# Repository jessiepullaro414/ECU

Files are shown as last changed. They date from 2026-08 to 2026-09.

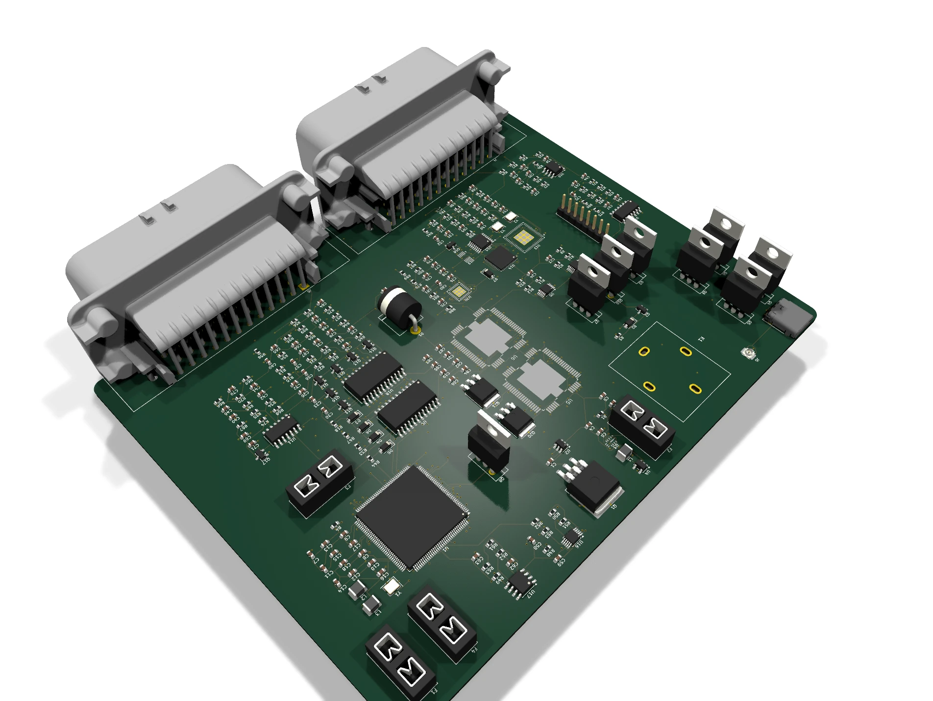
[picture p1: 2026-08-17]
ecu-pcb/render-angled.webp

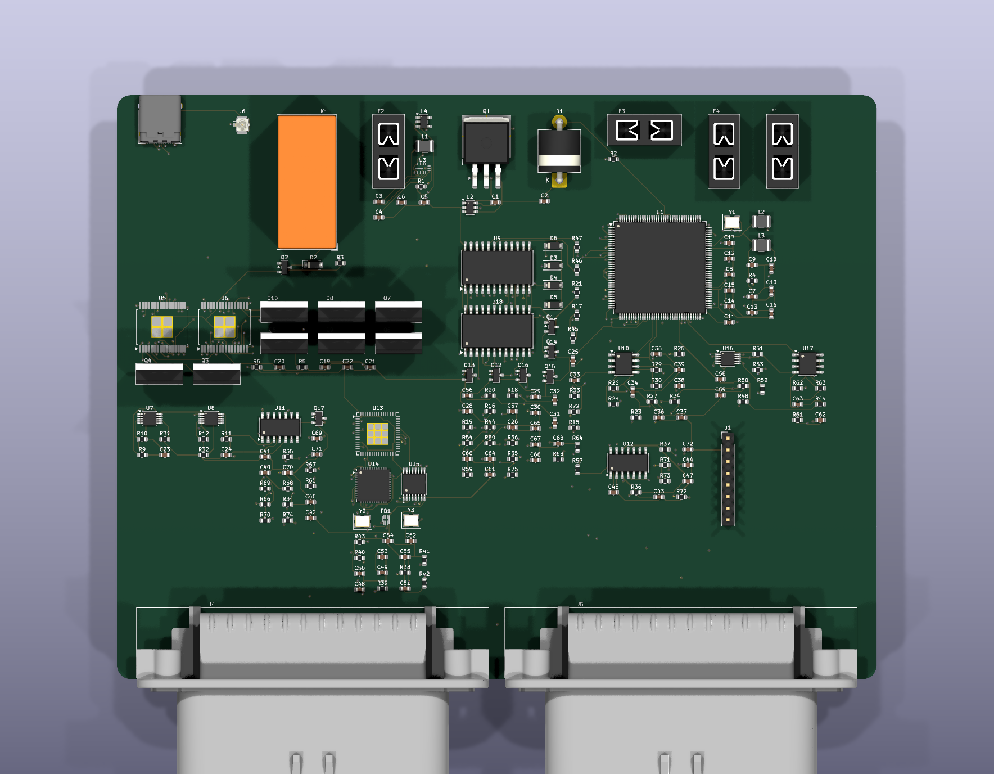
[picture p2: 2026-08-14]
ecu-pcb/ecu_8layer.png

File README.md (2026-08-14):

# ECU

This is the repo for the ECU PCB and firmware — an NXP MPC5606B-based engine
control unit, built with the same real, register/datasheet-verified
discipline throughout (see each subproject's own README for the full,
honest ledger of what's confirmed vs. still open).

- [`ecu-firmware/`](ecu-firmware/README.md) — MPC5606B (e200z0h core)
  register-accurate C/assembly firmware: clocks, SIUL2, DSPI, ADC, eMIOS
  injection/ignition timing, FlexCAN, INTC, SWT watchdog, and drivers for
  the L9779WD-SPI injector/ignition ICs and CJ125 wideband O2 front end.
- [`ecu-pcb/`](ecu-pcb/README.md) — 8-layer, 172.5×114.4mm KiCad board
  (224 parts / 236 nets), fully routed and DRC-clean, built with a
  script-driven generate → route → verify pipeline.

Run `python buildWholeProject.py` from this directory to build both:
schematic → PCB placement → autorouting → DRC for the board, and a
real per-file compile check for the firmware if a PowerPC-EABI/VLE
toolchain is available (see the script's own header for exactly what it
does and does not claim to produce).

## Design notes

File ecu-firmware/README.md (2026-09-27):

# ECU firmware — starting skeleton

Companion firmware project for [`../ecu-pcb`](../ecu-pcb) (the standalone
automotive ECU board). This is **not a working ECU** — it's a real,
compilable-shaped skeleton laying out the actual architecture, with the
hardware-verified facts (pin numbers, SPI protocol, register maps) kept
separate from the genuinely unimplemented parts, so the boundary between
"you can trust this" and "this still needs the reference manual open" is
explicit rather than blurred.

## What's real vs. what's a TODO

**Real, verified this session, safe to build on:**
- Every pin/channel number in [`inc/ecu_pins.h`](inc/ecu_pins.h) — a
  direct transcription of `../ecu-pcb/build_schematic.py`'s own
  `MCU_USED`/`MCU_EMIOS` dicts, the same source of truth the PCB was
  generated from.
- The MC33810 SPI frame format and fault-register map in
  [`inc/mc33810.h`](inc/mc33810.h) — read directly from the real
  datasheet (MC33810 Rev. 11.0, 8/2014) this session, not remembered.
- The confirmation that injector/ignition **firing** goes through the
  dedicated DIN0-3/GIN0-3 parallel pins, not SPI — SPI is
  configuration and fault-readback only. This matches how the board
  itself is wired and shapes the whole real-time architecture below.
- **The eMIOS unified-channel driver** ([`inc/emios.h`](inc/emios.h),
  [`src/emios.c`](src/emios.c)) — a real, working register layer, not a
  stub. Downloaded the actual NXP MPC5606BK Reference Manual (964
  pages) this session and confirmed, by rendering the real register
  diagrams to images and reading them directly (not the raw PDF text
  extraction, which shuffles this document's tables badly enough to be
  actively misleading): both eMIOS base addresses, the per-channel
  register offset formula, the complete EMIOSC[n] control-register bit
  layout, and OPWFMB mode's real encoding — the double-buffered PWM
  mode that's the actual reason `emios_set_pulse_width()` can safely
  re-arm a channel's pulse width mid-cycle without glitching whatever
  pulse is currently firing. `injection.c` now calls this for real.
- **Pin muxing is fully real now** ([`inc/siul2.h`](inc/siul2.h),
  [`src/siul2.c`](src/siul2.c)) — `pinmux_init()` configures every one
  of the 62 real pins in `ecu_pins.h`, not a mechanism waiting on data.
  Built by matching each pin's real 144-LQFP package number against
  Reference Manual Table 4-1 ("Functional port pins", pages 55-74),
  extracted via positioned-text coordinates (the flat text extraction
  shuffles this table's columns) and cross-checked against each pin's
  already-known real signal name from `ecu_pins.h` — all 62 matched
  exactly once, none guessed. Fell out a real, previously-unconfirmed
  formula: PCR index = port_offset×16 + pin-within-port (A=0…G=6),
  confirmed across every port this board's pins actually land on.
- **Clock/mode bring-up is fully real now** ([`inc/clocks.h`](inc/clocks.h),
  [`src/clocks.c`](src/clocks.c)) — `clocks_init()` is a complete,
  callable RESET→SAFE→DRUN→RUN0 sequence, not a stub. Real pieces:
  FMPLL's base address, IDF/ODF/NDIV divider fields, and S_LOCK;
  `ME_MCTL`'s two-write mode-transition mechanism (key `0x5AF0` then
  inverted key `0xA50F`); `ME_RESET_MC`/`ME_SAFE_MC`'s real SYSCLK
  field; and `ME_GS`'s status bits for polling a transition to
  completion. Two real findings worth recording:
  - Caught a real mistake before it shipped: FMPLL CR's upper 16 bits
    were first transcribed from text extraction alone and put S_LOCK
    at the wrong bit. Re-rendering that half as an image and reading
    it directly caught it.
  - `ME_DRUN_MC` and `ME_RUN0_MC`…`ME_RUN3_MC` genuinely have no
    SYSCLK field of their own (confirmed visually, not a page-break
    artifact) — resolved by reading section 8.4.3.12 "System clock
    switching": a mode with no SYSCLK field has nothing to switch to,
    so the source configured in SAFE mode simply carries forward.
    `clocks_init()` sets `ME_SAFE_MC.SYSCLK=PLL` once and relies on
    that.
  - `ME_GS`'s field-name row for bits 0:15 is genuinely missing from
    the source PDF (confirmed via raw positioned-text extraction, not
    a rendering issue) — recovered by cross-referencing the real field
    order (Table 8-4), each field's real bit-width, and the real reset
    value, which only fit together one way.
  - **`clocks_init()` is now actually called for real** from `main.c`'s
    `hardware_init()` (it wasn't, for the rest of this session — this
    was the single most-referenced open gap in the whole project, since
    it silently blocked a real DSPI baud rate, ADC power-up delay, and
    FlexCAN bit timing too). What unblocked it: `../ecu-pcb`'s own
    schematic already documents a real, deliberate 8 MHz crystal
    decision from the PCB design phase (not invented for this pass);
    combined with the FMPLL chapter's own real reference/VCO range
    constraints (4-16 MHz / 256-512 MHz, Section 6.7.2) and this
    manual's own confirmed 64 MHz max core frequency (its introduction,
    not assumed), real divider values fell out:
    `ECU_FMPLL_IDF/ODF/NDIV = 0/2/60` (`clocks.h`), giving a 60 MHz core
    clock — deliberately short of the 64 MHz max, not pushed to the
    edge, given the FMPLL chapter's own note that there's no hardware
    check against an out-of-range frequency.
  - **Follow-up in the same pass: MC_CGM's peripheral clock dividers,
    also real now** (`clocks.h`'s `CGM_SC_DC0` — Chapter 7, Figure 7-5,
    visually confirmed). The real 60 MHz core clock feeds three
    independently-divided "Peripheral Set" clocks; Table 6-1 confirms
    DSPI/FlexCAN are both Peripheral Set 2 and ADC/eMIOS are both
    Peripheral Set 3, and `CGM_SC_DC0`'s own real reset values (all
    three divider-enable bits = 1, all three divide fields = 0) mean
    both sets run **undivided at the real 60 MHz core clock** by
    default — this driver never writes that register, so the reset
    default is what's live. **Still open, honestly, not assumed:**
    each individual peripheral also has its own clock-gating selection
    (`ME_PCTL[n]`/`ME_RUN_PCn`, Chapter 8) that could in principle
    leave it un-clocked in RUN0 regardless of its Peripheral Set's own
    divider — this session located the real register addresses (cross-
    checked between two independent tables) but did not find/confirm
    `ME_RUN_PC`'s own reset bit values, so whether DSPI/FlexCAN/ADC/
    eMIOS are gated ON by default is plausible (matches every other
    "just works out of reset" MC_ME default seen this session) but not
    proven. This only affects whether a peripheral is clocked *at all*,
    not *at what rate* — the real 60 MHz figure above is unconditional
    once a peripheral is clocked.
    **Update (later pass): confirmed this really can't be proven from
    this source.** Chapter 8 (pages 144–177) was checked end to end —
    its own register-description subsections stop at
    `ME_HALT_MC`/`ME_STOP_MC`/`ME_STANDBY_MC`; there is no bit-diagram
    section for `ME_RUN_PCn`/`ME_PCTL[n]` anywhere in it, even though
    Table 8-3 lists their addresses and Chapter 6 explicitly promises
    "See the ME_PCTLn section in this reference manual for details" —
    a real, internal forward-reference in this manual to a section that
    was never actually written into this document. Genuinely absent,
    not a search miss; see `clocks.h`'s file header for the full note.
- **DSPI (SPI bus) is fully real now** ([`inc/dspi.h`](inc/dspi.h),
  [`src/dspi.c`](src/dspi.c)) — `dspi_init()`/`dspi_transfer()` are a
  complete, real, blocking master-mode driver, not stubs, and
  `mc33810_transfer()` (`mc33810.c`) calls it for real — no longer a
  stub either. Real pieces, all visually confirmed against Chapter 26's
  own register diagrams: MCR's MSTR/DCONF/MDIS/HALT/CLR_TXF/CLR_RXF,
  CTARn's CPOL/CPHA/FMSZ/baud fields, SR's TCF/TFFF/RFDF/w1c behavior,
  PUSHR/POPR's real 16-bit frame format. Three real findings worth
  recording:
  - This board's chip selects are plain GPIO, not DSPI's own hardware
    PCS0-5 lines — confirmed directly from Table 4-1 (none of this
    board's real CS pins carry a CS0_x-family alternate function).
    `dspi_transfer()` is therefore a bare frame primitive; CS toggling
    lives in `mc33810_transfer()`.
  - `SPI_SIN`'s (PA[12]) alternate function — flagged last pass as a
    corrupted, unconfirmed table cell — turned out not to be corrupted
    at all: `SIN_0` isn't AF-selected on this pin, confirmed by a
    document-wide search showing the string "SIN_0" appears exactly
    once in the entire 964-page manual (this same table row), unlike
    `SIN_3`/`SIN_4` which each have a real PSMI (Peripheral Selection
    Multiplex Input) register offering a genuine choice between two
    candidate pins. The existing GPIO-input configuration for this pin
    was already correct.
  - Found and fixed a real, previously-dormant bug: `ecu_pins.h`'s
    `PIN_SPI_CS_*` constants are 144-LQFP package pin numbers (matching
    every other constant in that file), but driving a pin as GPIO
    needs a PCR index — a different numbering, the same distinction
    `pcr_configure()` already carried a warning about. This was inert
    while `mc33810_transfer()` was a stub; wiring it up for real would
    have silently toggled the wrong pin. Fixed by adding
    `siul2_pcr_for_pin()` (`siul2.c`/`siul2.h`), a real runtime lookup
    against the same `PINMUX_TABLE` `pinmux_init()` already uses, so
    every caller keeps using the package-pin numbers `ecu_pins.h`
    already establishes as this project's convention.
  - The MC33810's real SPI clock mode (CPOL=0, CPHA=0) came directly
    from its own datasheet's Serial Clock Input description ("SI data
    is latched...on the rising edge of SCLK...SO...shifts out on the
    falling edge") — not assumed from a generic SPI default.
  - **`MC33810_CTAR0`'s baud rate is now real too** (a later pass, once
    the system clock gap closed) — 937.5 kHz, computed from the real
    60 MHz DSPI_0 peripheral clock and PBR's own real inline prescaler
    table (Table 26-5: values 2/3/5/7, not previously looked up).
  - **The "VDD=3.3V not confirmed" flag is resolved** (a later pass) —
    not by finding a separate 3.3V row, but by finding there isn't one:
    the datasheet's own Dynamic Electrical Characteristics table (Table
    5) states its values apply across "3.0V ≤ VDD ≤ 5.5V", a single
    spec covering this board's real 3.3V. The "1.0 MHz, 5.0V" figure
    previously read as a rating turned out to be the ATE test
    condition for guaranteed-by-design parameters (its own footnote
    says so), not a reduced real limit.
  - **Real `tLEAD`/`tLAG` values found, plus a previously-unknown real
    `tSTR` constraint** (same later pass) — Table 5's own "SPI DIGITAL
    INTERFACE TIMING" section: tLEAD ≥ 100ns, tLAG ≥ 50ns, and a real
    minimum 1.0µs gap required *between* separate transfers (tSTR,
    "Sequential Transfer Rate") that this project didn't know existed
    until this pass. `mc33810_transfer()` now runs a real, conservative
    busy-wait around every CS edge and between transfers, computed
    against this board's confirmed 60MHz core clock — closing what had
    been a standing TODO since the driver was first written.
  - **Most of Table 22's bit-level register layout is real now too**,
    not just the fault registers (a later pass) — found by rendering
    the register-address column header at the same crop/scale as each
    data row and tracing bit boundaries straight down against it (the
    same table had previously been dismissed as too garbled to trust).
    Mode Command and LSD Fault Command registers are fully real,
    high-confidence (`MC33810_MODE_*`/`MC33810_LSD_*`, `mc33810.h`).
    One real self-correction worth recording: a first pixel-count pass
    misplaced the LSD register's 3-bit fault-operation field at bits
    11:8 with a spare reserved bit at 7; re-deriving field widths from
    the total real bit budget (12 bits = 3+1+4+4, not 4+1+... which
    doesn't divide evenly) caught it and placed it correctly at bits
    11:9 with bit 8 reserved — the same "don't trust one read" discipline
    this project has used throughout catching itself again. Spark
    Command and DAC Command registers got real field *names* and
    *order* confirmed, but not exact bit-width splits for their
    multi-bit fields — left as real, generic 12-bit payload setters
    rather than fabricated sub-field macros.
  - **Update (later pass): a real address-space bug found and fixed,
    plus every remaining named MC33810 register gap closed.** Re-opened
    Table 21 ("SPI Command Message Set") — the datasheet's *write*
    command table, distinct from Table 22's *readback* table — and
    found it uses a completely different 4-bit top-nibble address for
    the same-named registers (e.g. Spark Command's real write address
    is `0x4`, not the `0x8` this file had previously taken from Table
    22). This wasn't a guess: Table 21's own "hex" column is internally
    self-consistent with its own 4 binary control-address bits on every
    row, and independently corroborated by repeated, non-tabular prose
    elsewhere in the datasheet ("...SPI Command Message Spark command
    (Command 0100, hex 4)..."). Table 22's addresses turned out to be a
    *separate*, real address space — the "Internal Register Address"
    used only inside the generic Read Registers Command's own payload
    to select what gets echoed back on SO, not a write address at all;
    its own header text says as much ("Next SO Response to HEX1 to HEX
    A Commands..."). The two spaces differ by a consistent, real `+4`
    offset for the 10 registers appearing in both. Every
    `MC33810_ADDR_*` constant except `ALL_STATUS` (which happens to
    coincide, `0x0`, in both spaces) was wrong for writing — renamed
    and split into `MC33810_WCMD_*` (real write address) and
    `MC33810_RADDR_*` (real internal register address) to make the two
    spaces impossible to conflate again. Along the way, also found and
    fixed a second, related bug: `mc33810_read_status()`'s All Status
    read was sending an all-zero `0x000` payload where Table 21 shows
    the real required command bits are `0xA00` — never actually
    triggered on real hardware, since no board has been fabricated yet,
    but a real bug regardless. Table 21's own bit-diagram also gave
    real, visually confirmed, full bit-width layouts for every register
    this project had previously left as generic 12-bit setters or not
    reached at all: Spark Command, DAC Command, GPGD Short Threshold
    Voltage Command, GPGD Short Duration Timer Command, GPGD Fault
    Operation Select Command, and PWM0-3 Freq & DC Command — closing
    every one of the previously-named MC33810 gaps in this ledger
    except the Clock Calibration Command's own separate 32µs CS-pulse
    protocol (real, documented, but genuinely needs a dedicated
    CS-pulse primitive this driver doesn't have yet). One real,
    deliberately unresolved discrepancy surfaced and was *not* silently
    picked: Table 10 lists DAC Command's Overlap Setting default
    (`<100>`) as 35%, but Table 21's own default annotation for the same
    field/same code says 50% — both numbers are transcribed honestly in
    `mc33810.h` rather than one being guessed as correct.
- **MC33810 replaced by ST L9779WD-SPI** ([`inc/l9779.h`](inc/l9779.h),
  [`src/l9779.c`](src/l9779.c)) — a real part-obsolescence event, not a
  scope choice: the MC33810 hit **Last Time Buy** status (confirmed via
  DigiKey: last order date 2027-04-30, ~205 units left, no
  NXP-recommended replacement — see the `mc33810-end-of-life` memory).
  No true pin/footprint-compatible drop-in exists (the whole "narrow
  scope" IC segment has moved to bigger, more integrated engine-
  management ICs); L9779WD-SPI (HiQUAD-64, confirmed **Active**, 500
  units in stock) was chosen as the best-targeted real alternative,
  with real precedent — [rusEFI](https://github.com/rusefi/kicad6-libraries/blob/main/L9779WD-SPI.kicad_sym)
  maintains a real KiCad symbol for this exact part. `mc33810.h`/
  `mc33810.c` are kept in the codebase as reference for their own real
  register-map research but are no longer called from `main.c`.
  Real, genuinely different SPI protocol (ST DocID027721 Rev 2, Section
  6.16, read via a Wayback Machine snapshot since ST's live site and
  every mirror tried blocked or timed out automated fetches this
  session): a **5-bit address + 8-bit data + odd-parity-bit** 16-bit
  frame, not MC33810's 4-bit-address/12-bit-payload split. Real,
  critical gotcha caught before it became a live bug: outputs default
  to disabled (`OUT_DIS=1`) after reset — any control-register write is
  silently ignored until the real `START_REACT` command's `START` bit
  is sent, which `l9779_init()` now does for both chips automatically.
  Real, confirmed register map for this board's actual scope:
  `CONTR_REG1` bits 7:4 = `CMD_OUT1-4` (this board's 4 real injector
  channels), `CONTR_REG2` bits 3:0 = `CMD_IGN1-4` (4 real ignition
  channels), `DIA_REG1` = 2-bit-per-channel fault readback for OUT1-4
  (00=short-to-ground, 01=open load, 10=short-to-battery, 11=OK) — same
  real fault-encoding shape as MC33810's, different bit positions. Real
  SPI timing (Table 53: fop max 8MHz, tlead 525ns, tlag 50ns, tcsn
  640ns, tnodata 1.5µs — all genuinely different numbers from MC33810's)
  lives in its own new `DSPI_0` CTAR2 profile (`dspi_configure_ctar()`),
  not reused from MC33810's CTAR0, via the same generic multi-CTAR
  mechanism CJ125 already proved. Real, deliberately unused features
  (available for a later, separate decision — see the plan file's
  redesign section): a built-in VRS sensor interface (only one channel
  per chip, can't replace all 3 of this board's MAX9924s anyway), a
  built-in CAN transceiver, K-Line, a main relay driver, and a 4-channel
  stepper driver.
  **Update (later pass): a real, critical correctness bug caught by
  reading the functional-description prose, not just the register
  tables.** Both LSa (`OUT1-5`, injectors) and the ignition pre-drivers
  (`IGN1-4`) are driven by the real logical **AND** of their own SPI
  control bit and their own dedicated parallel input pin (Sections
  6.8.1/6.10.1 — "They are driven by logical-AND of SPI control bit and
  dedicated parallel input," stated near-verbatim for both). MC33810
  worked differently (real, confirmed **OR** logic — the parallel pins
  alone were already sufficient). Since `CONTR_REG1`/`CONTR_REG2`
  real-reset to all-OFF, this board's real eMIOS-driven parallel firing
  pins would have toggled correctly on real hardware and still never
  fired anything, silently, until this was caught — `l9779_init()` now
  permanently enables all 4 real channels' SPI side at startup
  (`CONTR_REG1`/`CONTR_REG2` = `0x0F`), after which the parallel pins
  have full, unblocked real-time control. Same pass also confirmed
  `IGN1-4` is a genuine IGBT gate pre-driver — Section 6.10.1's own
  opening line: "They can drive IGBT Darlington transistors" — closing
  the real, previously-open question of whether it's a true drop-in
  match for MC33810's `GDx`.
  **Update (later pass): a real hardware dependency this driver can
  neither detect nor work around, worth knowing before debugging a
  "firmware sends everything correctly but nothing fires" symptom.**
  `IGN1-4`'s pre-drivers are supplied from the chip's own `VDD5` rail
  (Table 28 lists `VDD5` 4.9-5.1 V as their supply voltage range and
  specifies their short-to-battery detection thresholds relative to
  it), and `VDD5` is a linear regulator that only exists if an
  **external NMOS pass transistor** and an external charge-pump
  capacitor are fitted — the feature list says "5 V precision voltage
  regulator (±2%) with external NMOS", and Table 13 lists both as
  *required* external components. Those were genuinely absent from
  `ecu-pcb` until a later pass fitted them for real (`Q20`/`Q21` +
  `C82`-`C87`) — before that, this board would have had no ignition
  drive at all despite perfectly correct SPI and parallel-pin timing.
  Two more real behaviors now documented in `l9779.h` because they
  affect how firmware should interpret a dropout rather than what it
  should write: the charge pump's real default is *conditional*, not
  always-on (Section 6.7 — active below 12 V Ubat, or permanently via
  the `capful` bit; the default is genuinely correct for this board and
  needs no firmware action), and above a 28 V Ubat overvoltage it
  "will be switched off automatically no matter the `cp_off` bit
  status" — so ignition dropping out during a real load-dump excursion
  is designed protection, not a fault to retry through.
  **Real, named gaps, not guessed:** the parity bit's own calculation
  isn't confirmed from the text read this session — every frame sends
  parity=0, a real placeholder; whether `DO`'s data is same-frame or
  one-frame-delayed relative to `DIN`'s address isn't confirmed either
  (`l9779_read_dia1()` defensively reads twice, same pattern as
  `mc33810_read_status()`); IGN1-4's own real fault-diagnosis register
  wasn't located in the pages read, so ignition fault readback isn't
  implemented yet; and MC33810's real RSP/RSN (current-sense), FBx
  (coil/collector-sense), and `DRV_OUTEN` (shared kill-switch) pins have
  no confirmed L9779WD-SPI equivalent — flagged in `ecu_pins.h`'s
  `PIN_DRV_OUTEN` comment and the plan file's redesign section as open
  items for the `ecu-pcb` schematic-wiring pass, not resolved here. The
  PCB-side half of this redesign (new footprint, rewired schematic,
  re-routed board) is tracked separately in the plan file and hasn't
  started yet.
- **ADC is fully real now** ([`inc/adc.h`](inc/adc.h),
  [`src/adc.c`](src/adc.c)) — `adc_init()`/`adc_read_channel()` are a
  complete, real, blocking one-shot single-channel driver, not stubs,
  called from `hardware_init()` for both real ADC instances. Real
  pieces, visually confirmed against Chapter 28's own register
  diagrams: MCR's OWREN/MODE/NSTART/PWDN, MSR's status fields, CDR's
  VALID/OVERW/CDATA result format. One real finding worth recording:
  the MPC5606BK has **two independent ADCs** (10-bit `ADC_0`, 12-bit
  `ADC_1`), and which of three Normal Conversion Mask Registers
  (NCMR0/1/2) enables a given channel — and at which bit — follows a
  clean, real formula that fell out of visually confirming all three
  (Figures 28-38 through 28-41): bit *k* of NCMR*n* enables channel
  *(k + BASE)*, BASE = 0/32/64 for NCMR0/1/2. `adc_read_channel()` is
  channel-number-generic (takes a raw ADC channel, not a pin).
  - **The real pin → ADC-channel mapping is done too** (a later pass) —
    `adc_channel_for_pin()` (`adc.c`) real-maps every one of the 15
    real sensor pins in `ecu_pins.h`, and `read_sensors()` (`main.c`)
    now actually populates a real `sensor_readings_t` from them (raw,
    unfiltered — see that struct's own comment for the real filtering
    TODO). The channel-number formula this needed isn't stated
    explicitly anywhere in Table 4-1 — it came from Figure 28-1's own
    block diagram instead: `ADCx_P[n]` = channel *n* (same number on
    both `ADC_0`/`ADC_1` — confirmed the same physical pin wires to
    both), `ADCx_S[n]` = channel *32+n*. All 15 pins land on `ADC_1`
    (12-bit — free extra resolution, since every P[n] pin is wired to
    both instances) except `PIN_ADC_KNOCK1`, whose pad has no P[n] at
    all — only `ADC0_S[0]`/`ADC1_S[4]`, a real, confirmed case where
    the two instances' channel numbers for one physical pin genuinely
    differ (32 vs. 36), not a copy-paste.
- **Crank period tracking is fully real now** ([`src/injection.c`](src/injection.c)) —
  `crank_capture_isr()` computes the real, 16-bit-wraparound-safe tick
  delta between the two most recent crank edges (`ticks_between()`),
  and `cam1_capture_isr()` records a real "has a cam edge been seen"
  flag, both exposed to `main.c` via new real accessors
  (`injection_crank_period_ticks()`, `injection_crank_synced()`).
  `main.c`'s `update_engine_state()` now uses the sync flag for a real
  `ENGINE_STATE_CRANK_SYNC` → `ENGINE_STATE_CRANKING` transition — the
  first real state transition in the engine state machine. This math
  is genuinely frequency/tooth-count-agnostic (plain modular arithmetic
  over `emios.h`'s own confirmed 16-bit capture register width), so
  none of it depends on an unconfirmed number. Two real, complete
  conversion formulas were also added (`us_to_ticks()`,
  `angle_to_ticks()` in `injection.c`) but are deliberately **not**
  wired into `injection_arm_cylinder()` yet — see below for why.
- **FlexCAN is fully real now** ([`inc/flexcan.h`](inc/flexcan.h),
  [`src/flexcan.c`](src/flexcan.c)) — `flexcan_init()`/
  `flexcan_transmit()`/`flexcan_receive_poll()` are a complete, real,
  polled Message-Buffer driver (not the Rx FIFO engine — this board's
  telemetry use case doesn't need FIFO's ID filter table), wired into
  `hardware_init()` for both of this board's real, independent buses
  (CAN0 = FlexCAN_1, CAN1 = FlexCAN_4 — confirmed against
  `../ecu-pcb/build_schematic.py`'s own real routing, which also
  surfaced 4 pins — `PIN_CAN0_TX/RX`, `PIN_CAN1_TX/RX` — missing from
  `ecu_pins.h` since this file was first written; added for real this
  pass, along with their real pin-mux entries in `siul2.c`). Every
  register bit layout used (MCR, CTRL, the Message Buffer C/S+ID word)
  was visually confirmed against Chapter 25's own figures. Real
  findings worth recording:
  - A first pixel-boundary reading of the C/S+ID word figure put the
    PRIO/ID split one bit off; Table 25-4's own text ("only the 11 most
    significant bits (3 to 13) are used") caught and corrected it — a
    real example of this project's "cross-check, don't trust one read"
    discipline catching itself mid-session.
  - The real Rx message buffer **lock mechanism** (Section 25.5.7.3):
    reading an active Rx MB's C/S word locks it against being
    overwritten mid-read; the lock only releases on reading TIMER (a
    real "global unlock" register read) or another MB's C/S word.
    `flexcan_receive_poll()` does the real C/S-then-ID-then-data-then-
    TIMER sequence for exactly this reason — skipping the TIMER read
    would leave the MB locked and silently stop receiving forever.
  - **`FLEXCAN_CTRL_500KBPS`'s bit timing is real too** (a later pass,
    once the system/peripheral clock gaps closed) — a real, standard
    automotive 500 kbit/s target, computed from the real 60 MHz CPI
    clock and Table 25-10's real formulas: `PRESDIV=5` (Sclock =
    60MHz/6 = 10MHz), `PROPSEG=7`/`PSEG1=6`/`PSEG2=3` (20 time quanta
    per bit = exactly 500kbit/s, sample point at a real, standard 80%),
    `RJW=1`. All five field values confirmed within their real valid
    ranges (Table 25-10).
- **eMIOS crank/cam capture channel init is real now** (a later pass,
  `main.c`'s `emios_capture_init()`, called from `hardware_init()`) —
  step 4 of the roadmap, previously entirely unwired. Also resolved in
  the same pass: `EDPOL`'s real sense in SAIC (capture) mode — Table
  27-17's own explicit field description ("1 = Trigger on a rising
  edge, 0 = Trigger on a falling edge"), not just its bit position.
  The existing `emios_init_capture_channel()` logic already matched
  this real meaning before it was confirmed — now verified, not merely
  assumed. One real, honestly-flagged default remains, narrower now:
  this board's crank/cam sensors are real MAX9924 VR-to-digital
  conditioner ICs (`../ecu-pcb/build_schematic.py`), and which specific
  edge lines up with which specific reference tooth (an absolute phase
  question) wasn't found in this session's extraction of its datasheet
  — board/winding-specific, not generic. **Update (later pass):**
  rendered the MAX9924's own Figure 1 timing diagram as an image (text
  extraction didn't preserve the visual relationship between COUT and
  the VR signal) and confirmed COUT is simply a squared version of the
  VR signal's sign relative to BIAS — high through its whole positive
  half-cycle, low through its whole negative half-cycle — so *both*
  COUT edges land on a real zero-crossing, which the datasheet's own
  "Zero Crossing" section ties to "the center of the gear-tooth," not
  just one edge. Capturing on either edge is therefore equally valid
  and can't produce spurious captures; `emios_capture_init()`'s
  rising-edge default is a real, safe (if unproven-absolute-phase)
  choice, not a guess that might not even trigger correctly.
- **INTC (Interrupt Controller) is fully real now** ([`inc/intc.h`](inc/intc.h),
  [`src/intc.c`](src/intc.c)) — closing most of the gap flagged
  immediately above, in the same pass. `intc_init()`/
  `intc_register_isr()`/`intc_dispatch()` are a complete, real
  software-vector-mode driver, visually confirmed against Chapter 18's
  own register diagrams (MCR, CPR, IACKR, EOIR) and cross-checked
  address formulas. Two real findings worth recording:
  - **PSRn (priority select) is genuinely byte-addressable per source**
    despite its own figure grouping 4 sources per 32-bit word for
    display — the field-description text confirms it, the same real
    pattern already seen for `ME_PCTL[n]` (`clocks.h`).
  - **eMIOS interrupt vectors are shared two channels at a time in real
    hardware** — Table 18-10 lists one IRQ number per *pair* of
    channels (`EMIOS_GFR[F0,F1]`, `EMIOS_GFR[F2,F3]`, ...). This
    board's crank (channel 0) and cam1 (channel 1) captures are exactly
    such a pair (IRQ 141); cam2 (channel 18) shares IRQ 150 with an
    unused channel 19. `intc_isr_emios0_ch0_1()`/
    `intc_isr_emios0_ch18_19()` (`injection.c`) check each channel's
    own FLAG bit individually (`emios_flag_is_set()`, a new real,
    side-effect-free read added to `emios.h`) before calling the
    matching real `*_capture_isr()` — the INTC vector alone can't tell
    the channels apart. `main.c`'s `intc_setup()` registers both real
    vectors at deliberately high priorities (15 and 14 — Table 18-5).
  - Software vector mode's real mechanism turned out simpler than
    expected: reading `INTC_IACKR` returns the complete, ready-to-
    dereference address of the current interrupt's own vector-table
    slot (not just a raw source number needing manual math) —
    `intc_dispatch()` is a direct function-pointer call, no INTVEC
    extraction/shifting needed.
  - **What's still real and separately gapped, narrower now than
    before:** the e200z0h core's own exception-vector setup (`IVPR`,
    `IVOR4` — "External Input") and the actual assembly-level interrupt
    prologue/epilogue that makes real hardware jump into
    `intc_dispatch()` in the first place. This is genuinely outside
    portable C and typically supplied by toolchain startup code (e.g.
    S32 SDK) — no local PowerPC-EABI toolchain was available this
    session to write or check it against. Until it exists,
    `intc_dispatch()` is real, correct C that nothing yet calls from
    real hardware — but everything feeding INTO it (vector table,
    priorities, per-channel dispatch logic) now is.
  - **Update (later pass): this gap was researched further and narrowed,
    not closed.** Chapter 15 "e200z0h Core" — the manual's own core-
    architecture chapter — was read in full. Real findings: `IVPR` is
    confirmed SPR 63 (Figure 15-2, the same figure already used for
    `SRR0`/`SRR1`/`CSRR0`/`CSRR1`/`SPRG0`/`SPRG1`); the core is
    explicitly described as a **VLE-only** design (variable-length-
    encoding Power Architecture instructions, not classic/Book E
    encoding) — a real, previously-unflagged constraint meaning the
    still-missing interrupt prologue/epilogue assembly must target a
    VLE-aware toolchain mode (e.g. GCC `-mvle`), not generic PowerPC.
    The individual `IVOR0`–`IVOR15` SPR numbers, however, are confirmed
    **absent** from this specific 964-page manual — an exhaustive search
    for "IVOR" returns only 2 generic prose hits, no numbered table —
    and Section 15.5 says why: it explicitly defers the full
    architecture-defined register set to "the Power Architecture
    specification," a separate document not available this session. Per
    this project's no-guessing discipline, `IVOR4`'s number is
    deliberately still not written into `intc.h` even though it's
    well-established elsewhere in the wider e200/Book E family in
    general knowledge — this project only commits numbers verified from
    a real source actually consulted this session. See `intc.h`'s file
    header for the full writeup.
  - **Update (later pass): closed for real, via a real, different
    primary source.** The e200z759n3 Core Reference Manual (a sibling
    e200-family core, fetched via a real community.nxp.com forum
    attachment) has its own real Table 16 with an explicit `IVOR0`–`15`
    SPR list (`IVOR4`=SPR404, etc.). This isn't the MPC5606B's own
    e200z0h-specific manual, so this project's own discipline required
    real corroboration, not just "close enough" — and got it: every
    other SPR number this codebase had already confirmed from the
    actual MPC5606BK manual (`IVPR`=63, `PIR`=286, `SPRG0`=272,
    `SPRG1`=273) appears in the e200z759 manual's same table with the
    exact same numbers, four independent matches with zero mismatches.
    `intc_ivor_init()` (`intc.c`) now sets `IVPR`/`IVOR4` for real via
    GCC inline `mtspr`, and a real exception-entry assembly stub
    (`src/intc.S` — context save, call `intc_dispatch()`, context
    restore, return-from-interrupt) is written and wired in
    (`intc_setup()`, `main.c`).
    **Update (later pass): the VLE-mnemonic gap is closed too, and it
    caught a real bug.** The actual Freescale/NXP VLE Programming
    Environments Manual (fetched via Wayback Machine) has a complete,
    real VLE instruction mnemonic list (Appendix B) — checked every
    mnemonic `intc.S` uses against it directly. The first version of the
    stub used several bare Book E mnemonics (`lwz`/`stw`/`stwu`/`addi`/
    `rfi`/`mflr`/`mtlr`/`mfxer`/`mtxer`/`mfctr`/`mtctr`/`mtcr`/`bl`) that
    are genuinely absent from the real VLE instruction set and would not
    have assembled on this VLE-only core — a real, confirmed bug, not a
    hypothetical one. Replaced with the real, confirmed VLE forms
    (`e_lwz`/`e_stw`/`e_stwu`/`e_addi`/`se_rfi`/`e_bl`, plus `mtspr`/
    `mfspr`/`mfcr`/`mtcrf`, all independently confirmed real and
    unprefixed under VLE). Real, still-open, narrower risk: individual
    instructions' exact bit-encodings/operand-range limits weren't read
    this pass — a real VLE assembler (still not available this session)
    would be needed to catch a range/encoding mistake at assemble time.
    `e200z0h`'s own exact `IVOR4` field width also remains unverified
    (see `intc.c`'s own comment). This is real, substantive progress,
    not a full toolchain-verified guarantee.
- **CJ125 (wideband O2) driver is real now** ([`inc/cj125.h`](inc/cj125.h),
  [`src/cj125.c`](src/cj125.c)) — a whole new peripheral this session,
  built from the same real Bosch CJ125 datasheet already used during
  this project's PCB design phase. `cj125_init()`/`cj125_transfer()`/
  `cj125_read_ident()`/`cj125_read_diag()`/`cj125_handle_diag()` are
  real and wired into `hardware_init()`/`poll_driver_faults()` —
  closing a TODO that had been sitting since the MC33810 pass. The real
  register map, command bytes, and bit fields came from the datasheet's
  own SPI block-diagram figure (drawn, not stated as plain text — raw
  text extraction alone would have missed it entirely, same discipline
  as every MPC5606B driver header in this project). Two real findings:
  - **CJ125's response pipelining is genuinely different from the
    MC33810's** — confirmed directly from the datasheet's own Read
    Access timing diagram: the response DATA byte is for the *current*
    command, arriving in the same 16-bit exchange (only the leading
    status byte reflects the previous transfer), not delayed a whole
    transfer like the MC33810's pattern this project already knew.
    Missing this would have made every real register read return the
    wrong device's data.
  - **CJ125 needs a different, much faster real baud rate (2 Mbaud max)
    than the MC33810s share on CTAR0** — real, since both chip families
    share one DSPI_0 bus. This surfaced a real gap in the DSPI driver
    itself: `dspi_transfer()` only ever used CTAR0. Fixed generically,
    not with a CJ125-specific hack — `dspi_configure_ctar()`/
    `dspi_transfer_ctas()` (`dspi.h`/`dspi.c`) let any second real
    device share the bus on its own CTAR profile. `CJ125_CTAR1`
    computes a real, conservative 1.875 MHz SCK from the confirmed
    60 MHz DSPI_0 peripheral clock.
- **Sensor filtering is real now** (`main.c`'s `iir_update()`) — a
  simple, real, integer-only exponential-moving-average filter applied
  to every slow-moving sensor (MAP/TPS/IAT/CLT/VBATT/oil-fuel
  pressure/APP1-2/TPS1-2/EGT/ETC feedback) in `read_sensors()`.
  Deliberately excludes knock1/knock2: knock sensors are real
  piezoelectric pickups reporting a fast (multi-kHz) vibration
  transient, not a slowly-varying quantity, so the same EMA filter
  would smear out exactly the signal real knock detection needs — those
  two fields stay raw, unfiltered instantaneous reads, a real,
  intentional distinction, not an oversight. `SENSOR_IIR_SHIFT`'s
  specific time constant isn't tuned against a real running engine yet
  (can't be, until one exists) — same scope boundary as VE tables.
- **Real CLT (coolant temperature) sensor** — *the driver has since been
  folded into the generic sensor table (see "Analog sensors" below); the
  part research below is unchanged and its curve now lives in
  `config/engine.toml` as `[curve.gm_thermistor]`.* The board's CLT sensor was
  swapped to a real GM-style resistive sending unit (DIYAutoTune's
  "GM Closed Element CLT/Oil Temperature Sensor", the same real part/
  curve the sibling [thermo-pcb](https://github.com/jessiepullaro414/Thermo)
  project uses for its own engine-temperature sensor, and genuinely what
  production automotive coolant senders are). Real published curve
  (manufacturer's own page, only 3 points exist): -40°F=100.7kΩ,
  86°F=2.24kΩ, 210.2°F=177Ω. Since only 3 real calibration points exist,
  a single global NTC Beta constant across the full 250°F span would be
  a real approximation error (the two segments' own local Betas differ
  by ~8%, confirmed by computing both) — so a piecewise-Beta model was
  fit per real segment and used to derive a 14-row lookup table at
  design time (the derivation is preserved in
  `ecu-pcb/build_schematic.py` above R24/R25), with
  plain integer linear interpolation at runtime, no floating point,
  matching every other driver here. Readings outside the real calibrated
  range are clamped, not extrapolated (no real data exists past -40°F
  or 210.2°F) — which doubles as free open/short sensor-fault detection,
  same behavior the identical circuit already gives thermo-pcb. This
  redesign also caught and fixed a real hardware bug on the PCB side:
  both IAT's and CLT's pull-ups were wired to +5V despite this MCU's ADC
  domain genuinely running at 3.3V (no separate VRH/VRL pins) — a real
  latent over-voltage risk at cold temperatures, fixed in
  `ecu-pcb/build_schematic.py` (R24/R25 now pull up to +3V3). Not yet
  wired into engine-control logic (warm-up enrichment) — that's real
  engine-specific tuning data, same "needs a running engine" boundary as
  the VE/dwell tables, see `injection.h`'s own note.
- **Real IAT (intake air temperature) sensor** — *same note as CLT: the
  driver is now the generic sensor table, the research below stands.*
  Same session, same real part swap for the board's IAT sensor
  (DIYAutoTune's "GM Open Element IAT Temperature Sensor"). Real, honest
  discrepancy found and resolved while sourcing it, not glossed over:
  the IAT product page's own published 3-point curve shares its first
  two resistance values EXACTLY with CLT's own curve (100.7kΩ@-40°F,
  2.24kΩ@86-87°F) but disagrees on the third point's temperature for the
  identical 177Ω reading (146°F here vs. CLT's 210.2°F) — two genuinely
  different real sensors can't both be right about that. Real evidence
  this is copy-paste content contamination on DIYAutoTune's own IAT
  page, not two authentic curves: a leftover sentence on the IAT page
  itself calls it a "closed-element sensor" despite the product being
  titled/featured as open-element, and taking 146°F at face value would
  imply a per-segment NTC Beta more than 2x CLT's own for the shared
  -40..87°F segment (~7900K vs. ~3800K) — physically implausible for one
  real thermistor, versus CLT's own internally-consistent ~8% spread.
  Conclusion: genuinely the same underlying GM-pattern thermistor
  element as CLT, different physical package (open element for air vs.
  closed/NPT for liquid) — IAT reuses CLT's own
  already-cross-checked curve rather than the IAT page's likely-
  erroneous 146°F figure (kept, separately, as their rated maximum —
  DIYAutoTune's real stated max operating temp for this specific
  package, an honest fact worth keeping even though it's not used as a
  second clamp). R24=4.22kΩ (E96), deliberately different sizing from
  CLT's R25=1.00kΩ: IAT genuinely swings across nearly its whole real
  range in normal use (cold-soak to hot under-hood air), unlike
  thermostatically-regulated coolant, so it's sized via geometric-mean
  (sqrt(177Ω × 100.7kΩ) ≈ 4.22kΩ) for resolution across the full span
  rather than centered on one narrow sub-range.
- **Real EGT thermocouple front end** ([`inc/ads1118.h`](inc/ads1118.h),
  [`src/ads1118.c`](src/ads1118.c)) — a whole new peripheral, driven by
  a real qualification problem rather than a feature request. The
  board's EGT channel used an AD8495 thermocouple amplifier feeding the
  MCU's own ADC; that part carries no AEC-Q100 statement, and **no
  AEC-Q100 dedicated thermocouple amplifier IC exists at all** (MAX31855,
  MAX31856, AD8495, LTC2983, MCP9600 all checked). So the fix was
  architectural: a real AEC-Q100 Grade 1 ADC (TI ADS1118-Q1) reads the
  thermocouple millivolts directly over SPI, and cold-junction
  compensation moves into firmware using the device's own on-die
  temperature sensor. Every register fact here is from TI's SBAS457F,
  read this pass: Config register layout (Figure 44/Table 7), the
  32-bit transaction format (Section 9.5.7.1), and the cold-junction
  data format — 14-bit, **left-justified** in the 16-bit result,
  0.03125 °C/LSB, two's complement (Table 4, with TI's own worked
  examples confirming it). Two real findings worth calling out: the
  `NOP[1:0]` field **must** be `01` or the device silently ignores the
  config write entirely, and this part needs **CPHA=1** (it shifts DOUT
  on the rising edge and latches DIN on the falling), which is why it
  cannot share CJ125's CTAR1 despite both being comfortably slow enough
  — it takes its own CTAR3 at 1.875 MHz, well under this part's real
  4 MHz ceiling. Moving EGT to SPI also freed the analog pin it used to
  occupy (PD[9]) to become this device's chip select, so it cost no new
  MCU pin — `siul2.c`'s own earlier Table 4-1 check had already
  established those Port D analog pads are usable as GPIO.
  **The ITS-90 type-K conversion is now real too** — this was the
  driver's last open gap. The coefficients come from **NIST's own
  Standard Reference Database 60** (the online form of NIST Monograph
  175, DOI `10.18434/T4S888`). Reaching them needed a real browser:
  NIST serves those tables from a Blazor app that renders client-side,
  so plain HTTP fetches return an empty shell — which is exactly why an
  earlier pass recorded this as blocked and declined to invent numbers.
  Only the **inverse** coefficient set is used, because NIST's page
  rounds the forward ones to ~3 significant figures; since the curve is
  strictly monotonic, one table built from the inverse function serves
  both directions — forward for cold-junction compensation, reverse by
  binary search for the measurement.
  [`tools/gen_ktype_table.py`](tools/gen_ktype_table.py) generates
  [`inc/ktype_table.h`](inc/ktype_table.h) (130 entries, −40 to
  1250 °C) and **validates it against two reference points TI quotes
  independently from NIST**: 1250 °C → 50.644 mV and −40 °C →
  −1.527 mV. The generated table hits 50.6436 and −1.5272 — a genuine
  third-party check, not a self-consistency test. Worst interpolation
  error is 0.033 °C, inside NIST's own ±0.05 °C for the inverse
  function, and the integer round-trip the firmware actually performs
  was verified at 0.03 °C worst case. All integer maths, no FPU
  assumed.
- **Real watchdog (SWT) driver, closing a standing TODO** ([`inc/swt.h`](inc/swt.h),
  [`src/swt.c`](src/swt.c)) — a whole new, previously-untouched chapter
  (Chapter 33, "Software Watchdog Timer", 9 self-contained pages) read
  and implemented in full: real register map, real fixed service
  sequence (`0xA602`/`0xB480`), real field bit positions. One real,
  genuinely useful architectural fact this unlocked: SWT's counter
  clock is the undivided 128kHz SIRC, explicitly confirmed independent
  of this board's own FMPLL/system-clock configuration — meaning
  `swt_init()` can run (and does) as the *very first* thing in
  `hardware_init()`, before `clocks_init()`. That directly closes a
  previously-standing TODO in `main()`'s own comment ("a watchdog-forced
  reset instead of a silent halt" on a clock-bring-up failure) — the
  halt loop deliberately never services the watchdog, so a real,
  automatic reset now follows instead of an infinite silent spin.
  `swt_service()` is called once per real main-loop iteration, giving
  this firmware a genuine backstop against a hung main loop that the
  driver ICs' own hardware protections (MAXI/max-dwell, GPGD fault
  handling) can't provide, since those only catch output-stage faults,
  not a hung MCU. Real, deliberate, not-yet-measured choice: a 100ms
  timeout (12800 cycles at the confirmed 128kHz clock), more
  conservative than the chip's own 10ms reset default, since this
  firmware's real main-loop iteration time has never been measured (no
  systick/timer wired up yet). **Update (later pass): `ITR` is now a
  deliberate design choice, not a blocked gap.** SWT's real "Timeout"
  interrupt source was found in Table 18-10 (`SWT_IRQ_TIMEOUT` = IRQ 28)
  — real hardware interrupts can reach C code now (the e200z0h IVOR4
  gap is closed, see the INTC entry above), so nothing mechanical blocks
  wiring an `ITR=1` interrupt-then-reset ISR anymore. `swt_init()`
  deliberately keeps `ITR=0` (immediate reset) anyway: for a hung-
  main-loop backstop on a running engine, giving a genuinely stuck
  system a second timeout window to keep misbehaving is a worse real
  outcome than a fast, deterministic reset — a real safety trade-off,
  not an oversight. `SWT_IRQ_TIMEOUT` is documented and ready if that
  judgment ever needs revisiting. Window mode and keyed pseudorandom
  servicing remain deliberately unused too.

**Deliberately left as TODO, not guessed:**
- **A real CAN message ID/payload map.** `broadcast_can()`'s CAN ID
  (`0x100`) and single-byte `engine_state` payload are placeholders,
  not a defined protocol — this ECU's actual telemetry format is an
  application-layer decision, same scope boundary as VE tables.
- **RPM and any real angle→ticks conversion.** `us_to_ticks()`/
  `angle_to_ticks()` (`injection.c`) are real, correct, generic
  formulas, ready to use — but calling them for real needs two numbers
  this project doesn't have: the eMIOS peripheral's real tick frequency
  (same downstream MC_CGM peripheral-divider gap noted above for
  DSPI/CAN — the *core* clock is real now, this specific peripheral's
  clock still isn't derived from it) and the real crank trigger wheel's
  tooth count/pattern (an engine/sensor hardware choice, not a board
  one). **Both are closed now**: the eMIOS tick frequency is set by
  `[timebase]` in `config/engine.toml` and the time base is actually
  started (`emios_init_timebase()`), and the wheel geometry comes from
  `[crank]`. `injection_arm_cylinder()` converts properly and adds
  injector dead time centrally.
- **Which tooth/cylinder is at TDC** — *closed*. `crank_capture_isr()`
  finds the wheel gap, counts teeth from it, and walks the configured
  firing order to arm the cylinder that is due. What is still genuinely
  unknown is `CRANK_GAP_TO_TDC_DEG`: the angle between the wheel's gap
  and cylinder 1 compression TDC is a physical property of how the
  trigger wheel is fitted, and has to be measured on the engine with a
  timing light. The default in the config is a placeholder.
- Injected conversions, scan mode, DMA, interrupts, the analog
  watchdog, and CTU-triggered conversion (ADC) — real features with
  their own register groups, not touched by this pass's one-shot
  polled driver.
- ~~A real ADC power-up delay~~ — **resolved, a later pass, via a real,
  different primary source.** The Reference Manual explicitly deferred
  electrical timing specs to a separate Data Sheet document — this pass
  found and fetched that real document (MPC5606B Data Sheet, Rev. 5, via
  a Wayback Machine snapshot, since the live NXP URL 404'd the same way
  every other nxp.com doc did this session). Section 3.17 "ADC electrical
  characteristics" gives the real numbers: `tADC0_PU`/`tADC1_PU` (power-up
  delay) = 1.5µs max, `fADC0`/`fADC1` (analog clock) = 6–32MHz. Computed
  a real, worst-case-safe `PDED` value (`ADC_PDED_MIN` = 64 cycles,
  covering the fastest real `fADC` so the delay holds regardless of
  `ADCLKSEL`'s setting) and `adc_init()` now writes it to the real
  `PDEDR` register. **Update: `ADCLKSEL` itself is resolved too** —
  found back in the Reference Manual (Section 28.3.2/Table 28-11): a
  single MCR bit, 0 = half the Peripheral Set clock, 1 = equal to it.
  `adc_init()` never sets it, so it stays at its real default (0) —
  this board's real, exact `fADC` is `60MHz / 2 = 30MHz`, comfortably
  inside the confirmed range. The real exact minimum at that frequency
  would be 45 cycles; `ADC_PDED_MIN` stays at the more conservative 64
  rather than being retuned tighter. The old
  software busy-wait placeholder is gone, not just redundant, since
  `PDEDR`'s own real purpose is to make the hardware itself enforce this
  delay before the next conversion. (Also caught and fixed a real bug in
  this same ledger while re-checking: `PDEDR` was previously miscredited
  with a non-zero reset default alongside `CTR0-2` — re-verified against
  its own diagram, `PDEDR`/`DSDR` both reset to 0; only `CTR0-2`'s
  non-zero reset was ever real.)
- ~~`fmpll_wait_lock()` and `me_transition_to()` have no timeout~~ —
  **resolved** (a later pass): both now return 1/0 (success/timeout)
  after a real, bounded `CLOCKS_WAIT_ITERATIONS` count (`clocks.h`), and
  `clocks_init()`/`hardware_init()`/`main()` all propagate a real
  failure up to a genuinely minimal (halt-only) fault response — see
  `main()`'s own comment for why that's honestly named as minimal, not
  a complete fault strategy. `flexcan_transmit()` and
  `adc_read_channel()` got the same real, bounded-iteration-count
  timeout treatment in the same pass (`flexcan.h`/`adc.c`) — none of
  these are calibrated against a real time unit (this firmware has no
  systick/timer wired up yet to measure real microseconds against),
  just a real, generous iteration count at this board's confirmed
  60MHz core clock, honestly documented as such rather than implying a
  precision they don't have. This is what made it safe to finally call
  `broadcast_can()` from the real main loop (see below) — the whole
  reason a real CAN timeout was worth adding.
- **`ME_PCTL[n]`/`ME_RUN_PCn`'s real reset values** — real register
  addresses located (cross-checked between Table 32-5 and Table 6-1),
  but the actual per-peripheral clock-gating reset state wasn't
  found/confirmed this session (see `clocks.h`'s `CGM_SC_DC0` comment).
  Plausible peripherals are gated ON by default, not proven. **Update:**
  confirmed genuinely absent from this manual, not unresearched —
  Chapter 8 (pages 144–177) never contains a bit-diagram section for
  either register, despite two other places in the same document
  pointing to one that doesn't exist. Closing this for real needs a
  different real source than what's in hand.
- ~~`dspi_transfer()`'s real baud rate~~, ~~MC33810 tLEAD/tLAG timing~~,
  ~~VDD=3.3V confirmation~~ — all **resolved**, see the DSPI/MC33810
  "real" section above for the real numbers and findings.
- ~~The Spark Command and DAC Command registers' exact multi-bit field
  widths~~ — **resolved**, along with ~~GPGD short-threshold/duration
  timer commands~~ and ~~PWM0-3 freq/duty command~~ — see the MC33810
  "real" section above (Table 21's own bit-diagram gave every one of
  these for real, plus caught a real write-address-space bug in the
  process). The MC33810's Clock Calibration Command's own 32µs CS-pulse
  protocol is real and documented (`mc33810.h`) but still not
  implemented — genuinely needs a dedicated CS-pulse primitive, not
  just a command address.
- Everything engine-specific: firing order, VE/dwell/timing tables,
  fuel injector flow-rate scaling. These depend on the actual engine
  this ECU ends up on, not the board.

## Toolchain

**The firmware now compiles and links into a real, bootable image.**
`powerpc-eabivle-gcc` 4.9.4 (built for `ELe200`, the e200 core family
this MCU uses) builds all 18 source files — including the hand-written
VLE assembly in `startup.S` and `intc.S` — and links them against
[`link/mpc5606b.ld`](link/mpc5606b.ld) into `build/ecu.elf`. Run it
from the repo root:

```bash
python buildWholeProject.py --firmware-only
```

Current image: **12,932 bytes of flash** (of 1 MB) and **3,036 bytes of
SRAM** (of 80 KB) — plenty of headroom.

**Watch out for the wrong product.** NXP ships two separate IDEs both
called *S32 Design Studio*, split by architecture, and only one can
build this MCU:

- *S32 Design Studio for **S32 Platform*** is the **ARM** line
  (S32K/S32G). Its bundled GCCs are `arm32-eabi`/`arm64-eabi` only —
  no PowerPC target at all. Having it installed does not help.
- *S32 Design Studio for **Power Architecture*** (S32DS-PA) is the one
  this board needs. It lists MPC5606B as a supported device and ships
  `powerpc-eabivle` GCC under `Cross_Tools`.

`buildWholeProject.py` searches the real S32DS-PA install locations
automatically, and also finds a standalone `powerpc-eabivle-N_N`
toolchain tree; `ECU_FW_TOOLCHAIN_PREFIX` overrides both.

NXP's **TRK-MPC5606B StarterTRAK** kit ships real reference code for

NXP's **TRK-MPC5606B StarterTRAK** kit ships real reference code for
this exact part's peripherals (SCI/CAN/LIN/GPIO) — a genuine reference
worth pulling if any of the remaining named gaps above (real clock
divider values, bit-timing/baud-rate figures, CJ125 support) need a
second real source to check against.

## Engine configuration

Engine-specific facts live in **[`config/engine.toml`](config/engine.toml)**
— cylinder count, crank trigger wheel pattern, firing order, injector
dead time, ignition dwell. Edit that file and run:

```bash
python tools/gen_engine_config.py
```

which validates it and regenerates `inc/engine_config.h` (a generated
file — don't edit it directly). These were previously scattered as
"TODO, needs a real number" comments blocking the firing path, which was
the wrong shape for them: they are not facts to discover from a
datasheet, they are things the person fitting the ECU knows about their
engine.

Putting them in a file read by a generator — the same pattern the BOM
and the Type-K table use — also buys **real validation**. A `#error` in
a header can say "that's wrong"; the generator says *which* cylinder is
duplicated and which never fires:

```
engine.firing_order must list each cylinder 1..8 exactly once
  (repeated: [1]; never fired: [2])
```

That matters because a firing-order typo produces an engine that runs
*badly* rather than one that obviously doesn't run. It also checks teeth
divide 360, missing < teeth, cycle divides by cylinder count, and the
prescaler fits the 8-bit GPRE field.

**The ENGINE values are DEFAULTS, not measurements.** They describe a
common setup (36-1 wheel, 8 cylinders, the usual small-block firing
order) and have not been confirmed against any real engine, because
there isn't one yet. Getting the wheel pattern or firing order wrong
fires cylinders at the wrong time, which is how engines get damaged —
so treat that section as something to fill in deliberately. The
compile-time checks catch a config that contradicts *itself* (teeth that
don't divide 360, more missing teeth than teeth, a cycle that doesn't
divide by cylinder count); they cannot catch one that is simply wrong
for your engine.

Three things this unblocked:

- **Firing-order scheduling is implemented.** `crank_capture_isr()`
  finds the wheel's gap (a tooth period much longer than the last — with
  *missing* teeth removed the gap spans *missing+1* intervals), counts
  teeth from it, and walks the configured firing order to arm whichever
  cylinder is due. Nothing is armed until the wheel's position is known
  *and*, on a four-stroke, the cam has resolved which of the two
  revolutions this is — firing on an unsynced wheel means firing at an
  unknown angle. Verified by simulating the exact logic across four
  configurations (4-cyl 60-2, 6-cyl 36-1, 8-cyl V8, and a 2-stroke
  single that correctly skips cam sync): each fires every cylinder
  exactly once per cycle, in the configured order, evenly spaced.
- **The microsecond → tick conversion is now real.** `us_to_ticks()` and
  `angle_to_ticks()` existed but were never called; injector pulse
  widths were passed into the hardware as though microseconds were
  ticks. Both are wired in now, with injector dead time added centrally
  rather than left to each caller to remember, and a clamp so a pulse
  longer than the 16-bit channel can express is truncated visibly
  instead of silently wrapping to something much shorter.
- **A real bug: the eMIOS time base was never started.** Nothing ever
  wrote `EMIOSMCR`, and `GPREN`'s own field description is blunt —
  *"0 = Prescaler disabled (no clock)"*. The counter had no clock at
  all, so every capture would have read the same value with no error
  reported anywhere. `emios_init_timebase()` now sets the prescaler and
  enables it, following the manual's documented ordering, giving the
  1 MHz / 1 µs-per-tick base the injection maths assumes.
- **Speed-density fuelling is implemented** — `pulse_width_us` was being
  passed as a literal `0`, so every cylinder was scheduled with no fuel.
  [`src/fuel.c`](src/fuel.c) now does the real calculation at the moment
  a cylinder is armed: air mass in the cylinder from the ideal gas law
  (MAP × swept volume × VE ÷ R × intake temperature), fuel mass from the
  target AFR, pulse width from the injector's flow rate. All integer —
  no FPU is assumed anywhere in this firmware — with the intermediate
  air mass held in micrograms in a `uint64_t`, which is necessary rather
  than cautious: at 100 kPa on a 712 cc cylinder the numerator passes
  2×10¹⁰ before the divide, and a wrapped air mass produces a pulse
  width that looks plausible and is badly wrong.

### The VE table

Volumetric efficiency — the fraction of the cylinder that actually fills
— is the measured correction that makes the ideal-gas figure match what
the engine really inhales, and it is the whole reason a tuned map
exists. It lives in `[ve]` in `config/engine.toml` as an RPM × MAP grid
and is bilinearly interpolated. The generator checks both axes are
strictly ascending (the lookup walks them assuming that; a mis-ordered
axis would silently interpolate between the wrong cells), that the table
dimensions match the axes, and that no cell is outside 10–150 % — a VE
outside that is far more likely a typo than an engine, and catching it
here beats discovering it as a lean cylinder at load.

**The shipped table is a starting shape, not a tuned map.** It follows
the general behaviour of a naturally-aspirated engine — poor at low RPM
and light load, best in the midrange, falling off at high RPM — and
describes no particular engine. Running a wrong VE table lean under load
is how pistons get damaged.

Verified on the host against independently-computed floating-point
physics: all 40 table cells round-trip exactly, midpoints interpolate as
expected, off-axis queries clamp to the corner values rather than
extrapolating, and at 3000 rpm / 100 kPa / 40 °C the integer path gives
9272 µs against 9277 µs from the floating-point reference — a 0.05 %
difference, entirely integer truncation.

### The MAP transfer function, and a hardware bug it exposed

`fuel_map_kpa_from_adc()` converts raw counts to kPa across the two
calibrated points in `[map_sensor]`. Writing it is what surfaced a real
defect on the board: `MAP` — along with `TPS`, `APP1`, `APP2`, `TPS1`,
`TPS2`, `OILP` and `FUELP` — is a **5 V ratiometric** sensor feeding a
**3.3 V**-referenced ADC pin through nothing but a 1 kΩ + 22 nF RC
filter. No divider. Everything above 3.3 V converted to `0xFFF`, so the
MAP reading stopped at **~73 kPa of a 105 kPa range**: the ECU went
blind from part throttle upward, exactly where a lean mixture damages
pistons.

That has been fixed in `ecu-pcb` — each of those eight inputs is now a
2:1 divider (4.7 kΩ/4.7 kΩ, values derived against the ADC's own
sampling-network numbers rather than picked; see that project's README
for the full derivation), putting 5.00 V at 2.500 V. Which is why
`adc_counts_at_max = 3103`: 2.500 V of 3.3 V at 12 bits. **Change that
number if you change the divider** — it is the one constant in this file
that describes the board rather than the engine.

**A real bug this work caught**, in the firing-order scheduling
committed just before it: `event.cylinder` was being set to
`firing_order[i] - 1u`, but `cylinder_event_t.cylinder` is documented
1-based and `injector_ch[]`/`ignition_ch[]` are sized to match with a
deliberately-unused slot 0. So cylinder 1 indexed that sentinel — whose
base address is `0` — and cylinder 8 was never driven at all. That is
not "fires the wrong cylinder"; it is an eMIOS register offset written
into the flash boot sector. Found by simulating the ISR on the host and
noticing `ch0` in the armed-channel sequence. Fixed, and
`injection_arm_cylinder()` now rejects an out-of-range cylinder rather
than indexing the sentinel, so the same mistake can't reach a register
write again.

Two supporting pieces came with it. `injection_crank_rpm()` derives
engine speed from the tooth period, normalising the gap tooth's longer
period back to a single interval so RPM is valid at *every* tooth
including the one where wheel sync is established (host-checked: 2997
against a 3000 rpm stimulus, the residual being 1 µs tick
quantisation). And `injection_set_fuel_inputs()` publishes MAP and IAT
from the main loop, because the ISR must not do a blocking ADC
conversion itself — its whole budget at 6000 rpm on a 36-tooth wheel is
278 µs.

What is deliberately **not** implemented, because each needs a running
engine to calibrate and inventing a curve now would be guessing dressed
as configuration: warm-up enrichment from CLT, acceleration enrichment
from TPS rate of change, closed-loop trim from the wideband O2
controllers, and battery-voltage correction of injector dead time (the
board has the VBATT channel precisely for that; the single dead-time
figure in the config is a placeholder for the table).

## Ignition timing

Spark advance lives in `[ignition.advance]` in `config/engine.toml` as
an RPM x MAP table on its own axes, interpolated by the same
`table2d_lookup()` the VE table uses. `inc/ignition.h` / `src/ignition.c`
turn an operating point into an advance and an advance into a crank
angle.

**Before this, every cylinder fired exactly at TDC.**
`fire_angle_for_order_index()` returned the cylinder's nominal TDC angle
straight from the firing order and no advance was ever applied.
Combustion takes real time, so the charge has to be lit *before* TDC for
peak cylinder pressure to land just after it, where it can push. Firing
at TDC makes no useful power and pushes the engine toward detonation.

The table gets its own axes rather than borrowing the VE table's,
because fuel and spark are tuned against different breakpoints in every
real ECU. Adding it also collapsed a duplicate: the bilinear
interpolation was private to `fuel.c`, and a second copy would have been
a second chance for the two tables to disagree about what "halfway
between cells" means. It now lives once in `inc/table.h` / `src/table.c`,
with both tables emitted as `int16_t` cells so one implementation serves
both — spark advance can legitimately be **negative** (retarded past
TDC, which real engines do while cranking), which an unsigned cell could
not express.

**Two guard rails, both verified by deliberately breaking the config:**

A per-cell band, because over-advance is how pistons get holed:

```
ignition.advance.table[0][6] = 460 deg BTDC at 20 kPa / 5000 rpm
is outside -20..60 deg BTDC - almost certainly a typo
```

And a check that the largest advance still fits the scheduling window.
`crank_capture_isr()` arms a cylinder one firing interval before its
TDC, and the spark happens *advance* degrees before that TDC — so an
advance wider than the lead would need scheduling before its cylinder
was ever armed. On a four-stroke eight the interval is 90 degrees and
there is room; the check is reachable on short intervals, and a
two-stroke eight is the honest example:

```
ignition.advance peaks at 46 deg BTDC but cylinders fire every 45 deg,
which is also the scheduling lead. The spark would have to be scheduled
before its cylinder was armed.
```

The shipped table is a **starting shape, not a tuned map** — the same
warning the VE table carries, and it matters more here. Verified on the
host: all 40 cells round-trip exactly, midpoints interpolate as
expected, off-axis queries clamp to the corners, and the table's
physical shape holds across every row and column (advance rises with
RPM, falls with load). The angle wrap is checked too, since cylinder 1
sits at angle 0 and is therefore the common case rather than a corner
case: 26 degrees of advance on a 720-degree cycle gives a spark angle of
**694**, not a negative number.

### The output path is real now

**Two bugs, both upstream of everything else in the firing path.**

`emios_init_opwfmb_channel()` was **never called anywhere**. Only the
three crank/cam capture channels were initialised; all sixteen injector
and ignition output channels were muxed to their eMIOS alternate
function by SIUL2 but their unified channels sat in reset state, so
`injection_arm_cylinder()` was writing match registers on channels that
were in no output mode. Nothing would have fired.

Worse, and found while fixing that: **nothing drove counter bus A.**
Every timing function on this part - capture and output compare alike -
compares against a counter bus, and a bus is just one channel running a
modulus counter and broadcasting it. The capture channels always
selected bus A (`BSL = 00`, which is what their control word writes),
and bus A is driven by Unified Channel 23, which nothing configured. So
every crank and cam timestamp was read from a bus that never counted:
identical values every time, tooth period always zero, wheel never
synced. The engine could not have run even with the outputs fixed.

**DAOC, not OPWFMB.** OPWFMB is periodic PWM - `A` is the period, `B`
the width - so it free-runs and pulses regardless of where the crank is.
Double Action Output Compare is the one-shot mode: per Section
27.4.4.1.1.6 each comparator *"is enabled only after the transfer to
A1/B1 occurs and is disabled on the next match"*, so writing arms one
pulse, it fires once, and the hardware disarms itself until the next
crank event. With `EDPOL = 1` an A match drives the pin high and a B
match low, and mode entry leaves the output at the *complement* of
EDPOL - low - so initialising puts every injector shut and every coil
cold rather than in an undefined state.

That maps onto ignition exactly: releasing the coil **is** the spark, so
the B match is the event the advance was computed for, and A is one
dwell earlier. `DAOC = 0000110` and `MCB Up = 101000b` were confirmed by
rendering Table 27-21 rather than trusting text extraction - the same
render also showed `OPWFMB = 10110b0`, matching the constant this
codebase had already verified independently, which is what makes the
other two trustworthy.

**A third bug fell out of the counter bus.** MCB up mode counts
`1..A1` inclusive (Section 27.4.4.1.1.8: *"the MCB mode counts between
0x1 and A1 register value"*), so with `A1 = 0xFFFF` the modulus is
**65535, not 65536**. `ticks_between()` masked with `0xFFFF` and
therefore gained one tick every wrap. It is a conditional subtract now,
exact for any modulus and free of a divide.

**And a real scheduling constraint, found by simulation.** Arming was
silently failing above 3000 rpm: the range guard was correctly refusing
to schedule a spark the coil could not be charged for. On this
eight-cylinder engine at 6000 rpm cylinders fire every **2.5 ms** while
the configured dwell is **3 ms** - so the next coil must start charging
before the current one has fired. That is unavoidable, not a tuning
error, and a one-firing-interval arming lead cannot express it.
`ARM_LEAD_DEG` is two intervals now, which gives 5 ms at 6000 rpm.
Overlap is safe precisely because every cylinder owns its own eMIOS
channel.

Host-verified: at 3000 rpm ignition pulses are exactly the 3 ms dwell
and injector pulses exactly the computed width plus dead time; every
match value stays inside `1..65535`; pulses that straddle the counter
wrap (`on=57605 off=2243`) still measure the correct width; and 30
events arm per run at every speed from 450 to 6000 rpm.

### Dead time and dwell follow battery voltage

Both were single figures, and `config/engine.toml` already said in both
places that they wanted a voltage table. They are 1-D curves against
VBATT now, interpolated by `table1d_lookup()` - the same axis walk and
clamping the 2-D tables use, factored out so these two did not each grow
a private copy.

**Both are functions of supply voltage for the same physical reason.** An
injector has to build enough solenoid current to overcome the spring and
fuel pressure holding the pintle shut; a coil has to build primary
current to its design figure. Current in an inductor rises at V/L, so a
sagging rail makes both take proportionally longer. Measured against the
shipped placeholder curves:

| | 8 V (starter dragging) | 14 V (charging) | ratio |
|---|---:|---:|---:|
| dead time | 1700 µs | 880 µs | 1.93× |
| dwell | 5000 µs | 2800 µs | 1.79× |

The old fixed 1000 µs dead time would have **under-fuelled by 700 µs per
injection at 8 V** — every cylinder, every cycle, precisely when the
starter is dragging the rail down and the engine can least afford it.

A failed VBATT reading falls back to the nominal 14 V rather than zero,
in `main.c` and again as the module's own default. Zero volts would read
the *longest* entry off both curves and command a hugely overlong pulse
with an overcharged coil — the failure has to fall towards nominal, not
towards maximum.

**The generator checks the physics, not just the shape.** Both curves
must fall as voltage rises; a rising segment is not a tuning choice, it
is backwards:

```
ignition.dwell: 2500 us at 6.0 V but 3000 us at 8.0 V. Current builds
FASTER from a higher supply, so this curve must fall as voltage rises.
```

**This also closed the high-rpm dwell ceiling properly.** Dwell is a
fixed time while the gap between firings shrinks with speed, so above
about 8000 rpm the coil cannot fully charge in the time available. The
scheduler now **shortens dwell to fit** rather than refusing to schedule:
a weaker spark still fires, whereas refusing would act as an abrupt and
undocumented rev limiter. Host-verified — full 2.80 ms up to 7000 rpm,
then 2.69 ms at 8000 and 2.40 ms at 9000.

The curves are **placeholder shapes, not measurements**, flagged like the
VE and spark tables. Real numbers come from the injector's and coil's own
datasheets, or from a bench rig.

### The arming lead is sized from dwell, not fixed as an angle

The first version used a fixed 180-degree lead, and it could not schedule
anything below about **458 rpm** - which is every real cranking speed.
The obvious fix was to slow the timebase to buy counter range, but that
was treating a symptom.

**The lead is a time problem wearing an angle's clothes.** Coil dwell is
a fixed duration - 3 ms is 3 ms at any speed - while the crank covers
wildly different angles in 3 ms. A fixed angle lead must be sized for the
worst case (high rpm, where 3 ms is over 100 degrees) and is then absurd
everywhere else: at 150 rpm, 180 degrees means scheduling **200 ms ahead
to cover a 3 ms coil charge**, and the counter bus only spans 65.5 ms.

`arming_lead_deg()` sizes it from the dwell instead - whole teeth to span
the dwell (rounded up, since the selection test is in exact integer
degrees), plus the advance, plus one tooth of latency margin. It keeps
the 1 MHz timebase, keeps full resolution, and uses **less** counter
range than the fixed lead at every speed:

| rpm | fixed 180 deg | dwell-sized |
|---:|---:|---:|
| 150 | **cannot schedule** | 14 % of counter |
| 200 | **cannot schedule** | 10 % |
| 500 | 85 % | 19 % |
| 3000 | 13 % | 7 % |
| 7000 | 5 % | 5 % |

The generator reports both ends, computed with the firmware's own
arithmetic so the two cannot drift:

```
schedulable from 65 rpm up (counter bus spans 66 ms; lead uses 31% of it at 200 rpm)
dwell of 3000 us stops fitting the lead above about 7450 rpm - shorten
dwell there (a dwell-vs-rpm table) if that is inside your rev range
```

That upper bound is real physics, not a software limit: at 7450 rpm the
gap between firings is shorter than the coil needs, which is exactly why
a dwell-vs-rpm table exists.

**Two real bugs surfaced while proving this out, and both were latent -
neither was introduced by the adaptive lead.**

*The selection comparison was backwards.* It asked whether a cylinder's
TDC was **ahead of** the moving target, when it should ask whether the
target has just **swept past** the TDC. The two agree only when the
arming angle lands exactly on a tooth - which the old 180-degree lead
always did, by luck. Any other lead makes the target step over a TDC, and
an "is it ahead" test then never fires for that cylinder again.

*The selection window was one tooth wide, but the crank does not always
advance one tooth.* Across the wheel's gap it covers `missing + 1` tooth
intervals in a single edge, so on this 36-1 wheel the angles **350 and
710 degrees are never reported at all**. A cylinder whose arming angle
falls there simply never fires. The old lead of 180 degrees happened to
place all eight arming angles on real teeth; a lead of 100 degrees - what
the dwell calls for at 3000 rpm - puts two of the eight squarely in the
gap. The window is now as wide as the arc actually traversed.

Both were confirmed necessary by reverting each in isolation against a
**162-case sweep** (18 speeds x 9 load points, since the lead depends on
both). With the direction reverted, cylinders double-arm at 1800 and 6600
rpm. With the window reverted, five cases silently lose **two of eight
cylinders**. With both in place all 162 cases arm every cylinder exactly
once per cycle, verified over 21 engine cycles each.

That sweep is the reason it was worth testing across load and not just
speed: at 60 kPa the bug is invisible, and a speed-only sweep reports
everything clean.

### What is still not consumed

Injection **phase** — the crank angle at which the injector opens — is
still not a configured value. Pulse width is real and the injector is
scheduled on the counter bus like everything else, but it opens at the
arming point rather than at a calibrated angle. Injection phasing is a
genuine tuning parameter (it decides how much of the charge lands on a
closed valve) and no value for it has been established, so pretending to
one would be worse than saying this.

## Redundancy that can actually fail

The board carries two pedal channels and two throttle channels so a
single sensor failure can be caught by disagreement — on drive-by-wire
nothing mechanical links the pedal to the plate, so a sensor that lies
is a throttle that opens when the driver did not ask.

**The check would have been worth nothing as configured.** `app1`/`app2`
and `tps1`/`tps2` were identical — same band, same slope, same units.
Two channels with the same transfer function detect an open circuit and
nothing else: a stuck track, a track shorted to its neighbour, or a
cross-connected harness reads plausibly on *both*, the two agree, and
the comparison passes. A redundancy check that cannot fail is worse than
none, because it is believed. Production pedals ship a deliberately
dissimilar second track for exactly this reason.

So A3 became three things, not one.

### 1. Sensors have a signal band, not a rail-to-rail assumption

The linear kernel assumed 0 V → minimum and supply → maximum. Real
ratiometric sensors swing about 0.5–4.5 V, and the difference is not
cosmetic:

| MAP sensor output | firmware said | truth |
|---|---:|---:|
| 0.5 V (its minimum) | 19.5 kPa | 10 kPa |
| 4.5 V (its maximum) | 95.5 kPa | 105 kPa |

~10 % at both ends. The worse half is that **a broken wire pulls the pin
to 0 V and read as a perfectly valid 10 kPa** — there was no way to tell
"minimum pressure" from "disconnected" on any linear channel.

`signal_mv` states the real swing, and a `fault_margin_mv` band outside
it turns those dead zones into diagnosis: below the band is a broken
wire or a short to ground, above it is a short to the supply. That is
precisely *why* sensors are specified to swing 0.5–4.5 V instead of rail
to rail. Inside the band but past a calibrated endpoint still clamps —
that is tolerance, not a fault.

### 2. The second track of each pair is deliberately dissimilar

`app2` runs at **half slope** (0.5–2.5 V over the same travel); `tps2`
is **inverted** (4.5 V closed, 0.5 V open). Inverted is the stronger
form — no single failure makes a rising track and a falling track agree.

The generator **refuses** a pair whose transfer functions are not
distinguishable, so this cannot quietly regress:

```
redundant pair app1/app2 is not distinguishable: slopes differ by only
1.00x and run the same direction (need 1.5x, or opposite signs). Two
channels with the same transfer function detect an open circuit and
nothing else - a stuck or cross-connected track reads plausibly on both
and the check passes. Give one a half slope or invert it, as production
pedals do.
```

It also refuses a linear sensor with no `signal_mv` at all, rather than
silently reinstating the old assumption.

### 3. The check itself

`plausibility.c` walks the generated pair table, flags a pair whose
channels are out of band (`PLAUS_FAULT_RANGE`) or which disagree by more
than the configured tolerance (`PLAUS_FAULT_DISAGREE`), and **latches**.
Latching is deliberate: an intermittent connection that disagrees for
one sweep in a hundred is exactly the fault worth catching, and a
live-only flag would read clean by the time anyone looked.

Host-verified, including the case the old configuration could not catch
— a **cross-wired pedal harness**, where both pins carry track 1's
signal. With identical tracks the two channels read the same and agree
perfectly; with a half-slope second track they cannot.

**It detects and latches; it does not yet act.** There is no throttle
controller — the MC33926 H-bridge sits on the board unused — so nothing
can drop throttle authority in response. The rule that controller must
follow is written at the top of `plausibility.c` rather than left to be
rediscovered: limp position on a pedal fault, cut drive on a throttle
fault, and **never** fall back to whichever channel still looks healthy,
because the whole point of the pair is that one reading cannot be
trusted.

## Host tests

`python tools/run_host_tests.py`, and part of every `buildWholeProject.py`
run.

Nothing here can execute on the target — there is no board — so the only
way to run any of it is to compile the portable modules natively and
drive them with a hardware stub. That loop has caught, in order: a
`uint64_t` air-mass overflow that would have produced plausible-looking
wrong pulse widths; a cylinder off-by-one that wrote an eMIOS register
offset **into the flash boot sector**; a crash inside a safety check's
own error path; a scheduling window one tooth too narrow that silently
dropped two of eight cylinders; and a comparison written backwards that
only worked because one arming angle happened to land on a real tooth.

Every one of those was invisible to review and invisible to the
compiler.

They used to be written to a scratch directory, which is wiped between
sessions — so each of those bugs was found by a test that no longer
existed the next time anyone looked. They live in `test/` now. A
regression that has to be re-derived is not a regression test.

| test | covers |
|---|---|
| `test_sensors.c` | conversion kernels, checked against the *retired* CLT/IAT drivers |
| `test_tables.c` | VE, spark, dwell curves; integer fuel path vs floating-point physics |
| `test_plausibility.c` | redundant-pair faults, including the cross-wired harness |
| `test_scheduling.c` | 162 cases — 18 speeds × 9 loads — every cylinder armed once per cycle |

The scheduling sweep covers **both** axes on purpose: the arming lead
depends on dwell *and* advance, so a lead that lands cleanly at one load
can land on the trigger wheel's missing tooth at another. A speed-only
sweep reports everything clean while two of eight cylinders never fire.

## Analog sensors

Every analog channel is described in `config/engine.toml` and converted
by one table-driven module (`inc/sensor.h`, `src/sensor.c`) with three
kernels — `linear`, `voltage`, `thermistor`. Adding a sensor is a config
edit, not a new `.c`/`.h` pair.

This replaced `clt_sensor.{c,h}` and `iat_sensor.{c,h}`: **405 lines
that differed in a pull-up value, a lookup table, and the prefix on
every identifier.** Meanwhile eight channels — TPS, OILP, FUELP,
APP1/APP2, TPS1/TPS2, VBATT — had no conversion at all and were still
raw ADC counts in the main loop, each of which would have wanted its own
file pair. The pattern did not scale. All eleven channels now report
engineering units.

Four things this buys beyond tidiness, and they are the actual reason to
do it:

**The divider stops being a magic number.** Each channel names the real
resistors in front of it and the generator computes where full scale
lands in ADC counts. `MAP_ADC_AT_MAX = 3103` used to be typed in by hand
and would have gone stale the moment the board changed. The generator
now derives it — and derives it *correctly*: the divisor is 4096, not
4095, because the data sheet's Figure 22 defines `1 LSB ideal =
AVDD / 4096`. Using the maximum code instead would bias every reading by
one count. Negligible against a ±6 LSB TUE, but wrong for a number whose
whole purpose is being derived rather than guessed.

**It cross-checks the board.** The generator reads
`ecu-pcb/build_schematic.py` and compares every declared resistor against
the real reference designator — 18 of them at present. Config and board
cannot drift apart silently:

```
sensor.map.divider.r_bottom says 10000 ohm but R94 on the board is
4700 ohm (ecu-pcb/build_schematic.py). One of the two is stale - the
firmware and the board must agree.
```

If `ecu-pcb` isn't beside this project the check is skipped and says so,
so the firmware still builds standalone.

**It refuses a divider that would clip.** This is not hypothetical — it
is the bug this board actually shipped, where eight 5 V sensors fed a
3.3 V ADC through nothing but an RC filter and MAP stopped reading at
~73 kPa of its 105 kPa range. That configuration is now unrepresentable:

```
sensor.map: a 5000 mV sensor through NO DIVIDER AT ALL - it is wired
straight to the pin puts 5000 mV on a pin referenced to 3300 mV.
Everything above the reference converts to full scale, so the top 34%
of this sensor's range would be unreadable.
```

**One unit convention.** Everything is hundredths of a degree Celsius.
The old drivers worked in tenths of a degree *Fahrenheit* while the EGT
path worked in centi-Celsius, which put a `(tenthF - 320) * 50 / 9`
conversion in the middle of the fuel calculation. That is gone.

### One curve, two sensors

CLT and IAT share a single `[curve.gm_thermistor]` rather than carrying
duplicate tables, and that is a finding rather than a convenience.
DIYAutoTune's IAT page publishes a third curve point (146 °F at 177 Ω)
that contradicts the CLT page (210.2 °F at the same 177 Ω) while the
first two points are identical. Two different sensors cannot both be
right about that. The IAT page's own text calls the product a
"closed-element sensor" while selling it as open-element — leftover copy
from the CLT page — and taking 146 °F at face value implies a
per-segment Beta more than twice CLT's own over the shared segment,
physically implausible for one thermistor. Conclusion: the same GM
element in two packages. The config structure now says so directly.
DIYAutoTune's 146 °F is kept as their stated *maximum rated* temperature
for the open-element part, which is a real and different fact.

### What is deliberately not in the table

EGT is a thermocouple behind an SPI ADC needing cold-junction
compensation and a NIST ITS-90 polynomial; knock is a raw AC signal
wanting a windowed transform, not a scalar conversion. Both stay
bespoke — forcing either in would make the table lie about what it can
do.

**The throttle, pedal and pressure ranges are placeholders**, flagged as
such in the config the same way the VE table is. A real TPS/APP does not
swing the full 0–5 V (typically ~0.5–4.5 V) and production practice is to
*learn* the closed and wide-open endpoints rather than trust a datasheet;
no specific oil or fuel pressure sender has been chosen. Those channels
report something meaningful now, but none of them is a calibration.

Verified on the host against the drivers they replaced: thermistor
resistance is bit-identical, temperature agrees within **0.04 °C** (pure
rounding of the old Fahrenheit curve), and MAP reproduces the retired
`fuel_map_kpa_from_adc()` exactly. VBATT reads 14.02 V at a plausible
charging count. Open circuit, bad channel id, and resistance-on-a-
non-thermistor all return their documented sentinels.

## Boot and startup

Two files carry everything between reset and `main()`, and both are
built from the MPC5606BK Reference Manual rather than a vendor template.

**[`link/mpc5606b.ld`](link/mpc5606b.ld)** — code flash 1 MB at
`0x0000_0000`, L2SRAM 80 KB at `0x4000_0000` (Table 31-3). It also
carries two `ASSERT`s that turn silent runtime corruption into
link-time errors, the useful one being an SRAM overflow check so
`.data + .bss + stack` can never quietly exceed 80 KB.

**[`src/startup.S`](src/startup.S)** — the reset entry. Two parts of it
are genuinely easy to get wrong and expensive to debug:

1. **The boot header.** Chapter 5 / Figure 5-2: the SSCM scans each
   boot sector for `BOOT_ID = 0x5A` in bits 8:15 of the word at the
   sector base, then jumps to the 32-bit vector at offset `0x4`.
   PowerPC numbers bits MSB-first, so that word is **`0x005A0000`**.
   Get it wrong and the SSCM finds no valid sector across all five,
   hands over to the BAM, and parks the core in static mode — the chip
   never runs your code and gives no other symptom. The build verifies
   the word actually landed rather than assuming it did.
2. **SRAM ECC initialisation, before the stack exists.** Section 31.5
   is explicit that because ECC syndrome bits power up random, SRAM
   "must be initialized by executing 32-bit write operations prior to
   any read accesses" — including implicit reads caused by sub-32-bit
   writes. A stack frame is read back on the way out, so the stack
   cannot be touched until this is done. The init therefore runs out of
   registers only: no stack, no reads, no calls. It uses `e_stmw` to
   write all 32 registers (128 bytes, 32-bit aligned, even count, as
   Section 31.6 requires) per iteration — 640 iterations covering
   exactly 80 KB, which the disassembly confirms.

`startup.S` also supplies a no-op `__eabi`, which GCC calls at the top
of `main()` on PowerPC EABI targets; the small-data bases (`r13`/`r2`)
and `.data`/`.bss` init it would normally arrange are already done
explicitly in the startup path.

## Real-time architecture

Two timing domains, deliberately kept separate (see `src/main.c` and
`inc/injection.h` for the full reasoning):

1. **Interrupt context** — crank/cam capture only. Decides fire angles,
   arms the next eMIOS event. Nothing else should run here.
2. **Main loop** — ADC sampling, table lookups, MC33810/CJ125 SPI
   polling, CAN, fault monitoring. Feeds the *next* interrupt-context
   decision; never blocks waiting on the current one.

No RTOS in this skeleton — the actual hard-real-time work (pulse
timing) is done by the eMIOS hardware once armed, not by software
scheduling, so a plain main loop is a reasonable real starting point
(the same structure most bare-metal EFI firmware uses). If task
isolation becomes worth the complexity later, **Erika Enterprise** is
the real open-source option for this MCU's e200 core — OSEK/VDX
RTOS, GPL, with confirmed Power-Architecture e200 support for several
MPC56xx variants (MPC5674F, MPC5668G, MPC5643L). The MPC5606B itself
isn't confirmed on their supported list — same "verify, don't assume"
gap as everything else here.

## Open-source reference material (not reusable code)

**rusEFI** is the closest real open-source EFI project in spirit — the
same MC33810 driver-IC pattern this board uses — but it targets STM32
only; there is no Power Architecture support. Its actual firmware code
won't port. Its documented *algorithms* (VE table interpolation,
cranking/warm-up compensation, closed-loop O2 trim structure) are
genuinely worth reading as a reference while writing the table-lookup
logic this skeleton's `update_tables()` stub leaves open.

## Known open items

- **All six driver roadmap steps have real work landed** (see above):
  eMIOS, SIUL2/pin-mux, clock/mode bring-up, DSPI, ADC, crank-period
  tracking, and FlexCAN. Step 4 (eMIOS) is partial (crank/cam capture
  channel init is real, injector/ignition arming deliberately deferred
  — needs real tick values this project doesn't have). Step 5 is
  partial too (period tracking is real, RPM/angle-to-ticks conversion
  is correctly formula'd yet deliberately not wired in). The clock
  chain is now real end to end for DSPI/CAN (60MHz core →
  confirmed-undivided peripheral clock → real, computed 937.5kHz SPI
  baud rate and 500kbit/s CAN bit timing). INTC (Interrupt Controller)
  is real too now — real vector table, priorities, and per-channel
  dispatch for this board's two real, shared eMIOS capture vectors.
  Every blocking wait that used to have no timeout (`fmpll_wait_lock()`,
  `me_transition_to()`, `flexcan_transmit()`, `adc_read_channel()`) now
  has one — real, bounded, iteration-count-based (not calibrated
  against a real time unit, no systick/timer wired up yet, honestly
  documented as such). ~~What's left: ADC's own real settling-TIME
  figure~~ — resolved, see the ADC entry above (real MPC5606B Data
  Sheet, real `PDEDR` value now written). What's left: the
  still-honestly-unconfirmed `ME_PCTL`/`ME_RUN_PC` per-peripheral
  clock-gating reset values (plausible but not proven — checked this
  same new real MPC5606B Data Sheet for `ME_PCTL`/`ME_RUN_PC` too;
  genuinely absent from it as well, real confirmed, not just unfound —
  this specific gap needs a different real source than either document
  in hand). **Update: the e200z0h core's own
  `IVPR`/`IVOR4` exception-vector setup is real now too** (`intc_ivor_init()`,
  `intc.c`, plus a real assembly entry stub, `intc.S`) — see the INTC
  entry above for the full provenance and its own honestly-flagged,
  still-open risks (VLE-encoding and exact `IVOR4` field width, neither
  independently verified this session, no local PowerPC-EABI/VLE
  toolchain available to check either against). The CJ125 (wideband O2) driver is
  real now too, a whole new peripheral this session, closing the
  MC33810-pass TODO — see above.
- `injection_arm_cylinder()` converts microseconds to eMIOS ticks for
  real and adds injector dead time centrally; `crank_capture_isr()`
  decodes the missing-tooth wheel and arms the cylinder due next, with
  a real speed-density pulse width from `fuel.c`. All three previously
  needed numbers (eMIOS tick frequency, wheel geometry, firing order)
  now come from `config/engine.toml` (see above).
- `broadcast_can()` is now called from the real main loop (see above) -
  `flexcan_transmit()`'s real timeout made that safe.
- MC33810 SPI transfer (`mc33810_transfer()`) is implemented with a
  real, conservative baud rate and real tLEAD/tLAG/tSTR timing margins
  (see above) - both previously-open gaps now closed.
- Firing order and the VE table are real and configurable
  (`config/engine.toml`, see above), with the values shipped as
  documented **defaults, not measurements**. No ignition-timing table
  and no dwell *table* exist yet (dwell is a single configured figure);
  both are engine-specific and want a running engine to tune against.
- **The real CJ125 INIT_REG1/2 byte values for this board's actual
  running configuration** — `cj125_write_init1()`/`cj125_write_init2()`
  are real, generic byte setters, but which gain range (`VL`) matches
  the real LSU4.2 sensor's calibration and which pump-reference-current
  code (`PR0-3`) to use needs either a fuller application-note
  extraction (the PRx-to-µA transfer function wasn't in this session's
  excerpt) or bench calibration against a real sensor — neither done.
  Nothing calls the write functions yet as a result. **Update (later
  pass):** a web search surfaced a claimed conflicting value
  (`0x88` for "normal, gain=8×" in a real, widely-used open-source EFI
  project's driver code) — rather than trust an AI-summarized secondhand
  claim, it was checked directly against the real Bosch datasheet's own
  `INIT_REG1` diagram (already rendered this project, `cj125_spi_page.png`).
  The primary source re-confirms this file's existing bit positions
  exactly (`x|PA|x|RA|x|LA|x|VL`, bits 7/5/3/1 reserved) — the claimed
  `0x88` never actually got verified from source (the real fetch was
  blocked), so it doesn't count as a real contradiction. `cj125.h` now
  documents the real, generic formula for a "normal, gain-8×,
  measurement mode" byte (`PA=1` alone = `0x40`) — still not this
  board's specific chosen configuration, that part of the gap remains.
- The CJ125's own real command-byte "hec" (header error check)
  generation algorithm — not reverse-engineered; this driver uses the 6
  real command byte values directly rather than needing it, but no 7th
  command can be synthesized without finding the real algorithm.
- Lambda/AFR conversion from the CJ125's real UA/UR analog outputs —
  those are separate real ADC channels, not covered by this SPI-only
  driver, and weren't cross-checked against `ecu_pins.h` this session.

## Reference material used this session

The real NXP MPC5606BK Microcontroller Reference Manual, Rev. 2,
05/2014 (964 pages) — the primary source for everything in `emios.h`,
`siul2.h`, `clocks.h`, `dspi.h`, `adc.h`, `flexcan.h`, and `intc.h`. Not re-hosted here; if you need it again, NXP's own direct
link 404s in some environments (bot-protected), but it's mirrored at
`dtsheet.com/doc/2288517` and was also fetched successfully via a
regular browser session pointed at NXP's own
`docs/pcn_attachments/16234_MPC5606BRM_Rev2.pdf` when curl's request
was blocked.

The real Bosch CJ125 datasheet (Robert Bosch GmbH, 04/2006) — the
source for `cj125.h`/`cj125.c`, the same real datasheet already used
during `../ecu-pcb`'s own PCB design phase (see that project's own
schematic comments). Landed via a Wayback Machine mirror after direct
fetches were blocked, same real pattern as this project's other
datasheets.

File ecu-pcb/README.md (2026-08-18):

# ECU — standalone automotive engine-management ECU

Companion KiCad project for a from-scratch standalone ECU: drives fuel
injectors and ignition coils directly, closed-loop on engine sensors,
usable across 4/6/8-cylinder engines from a single board, with both BLE
and USB-C as full (not partial) wireless/wired firmware-flashing paths.

Sibling project to [`../manifold-pcb`](../manifold-pcb) (a smaller
Arduino-Nano-pinout automotive sensor board) — this project reuses
Manifold's script-driven, kiutils + kicad-cli-verified generation workflow
directly rather than reinventing it, but is a separate, much larger board:
new directory, new schematic, not built on top of Manifold's layout.

**Status: schematic complete, board placed + fully routed + DRC-clean,
BOM done.** Steps 2-10 are all done. The board is **165.8 × 130.1 mm,
8 layers, 243 footprints, 243 nets**, fully routed (0 unrouted) with GND
planes poured on In1/In3/In6.Cu and +3V3 on In4.Cu — 3729 track
segments and 521 vias. Real `kicad-cli pcb drc` reports **0 errors and
0 unconnected items** — the only remaining findings are the same benign
`lib_footprint_mismatch` warnings this project (and Manifold before it)
has always carried, now 19 of them.

Routing on a board this dense (242 nets, a 0.5mm-pitch H-bridge QFN, 8
layers) sits right at FreeRouting's practical convergence limit:
repeated full regeneration+route cycles land at score ~992-993 with
0-3 residual nets that vary run to run — ordinary autorouter variance,
not a stuck design, and this specific committed board is one of the
runs that landed at a genuine, DRC-verified zero. Widening part spacing
to force convergence was tried and **ruled out** — see "Known open
items".

**Every active part on this board is now automotive-qualified.** The
three that once weren't are resolved: MC33926 was always AEC-Q100
Grade 1 (a stale datasheet revision hid it), the L9779's `VDD5` pass
NMOS became the AEC-Q101 `STD20NF06LAG`, and the unqualified AD8495
thermocouple amplifier was replaced architecturally by an AEC-Q100
ADS1118-Q1, because no qualified thermocouple amplifier IC exists to
swap it for.

The **BOM is generated, not hand-kept** — [`build_bom.py`](build_bom.py)
reads the schematic directly and renders
[`ECU_BOM.html`](ECU_BOM.html), a standalone parts-list page. What
remains before fab is a purchasing pass for live pricing and stock, and
hand-layout of the RF section, which cannot be machine-routed.
**Every part on the board is now a real, specific part** — the 2.4 GHz
balun was the last placeholder, now resolved to a Johanson
`2450BM14G0011T-AEC`.
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

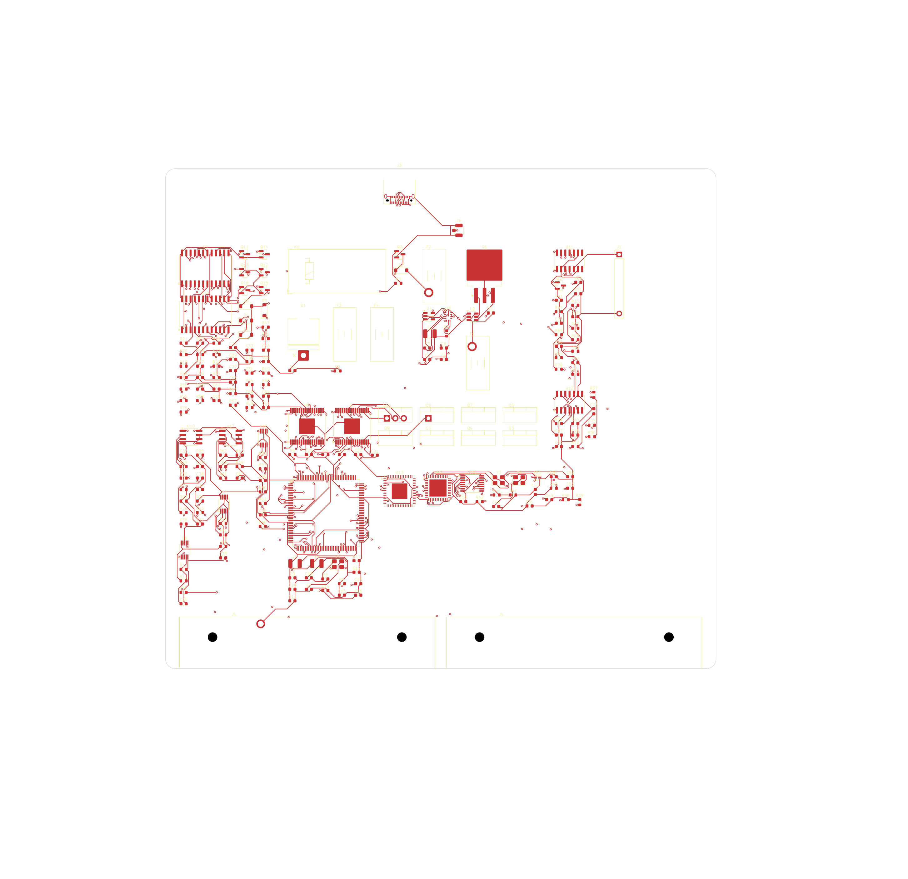
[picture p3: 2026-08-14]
ecu-pcb/ecu_final_2d.png

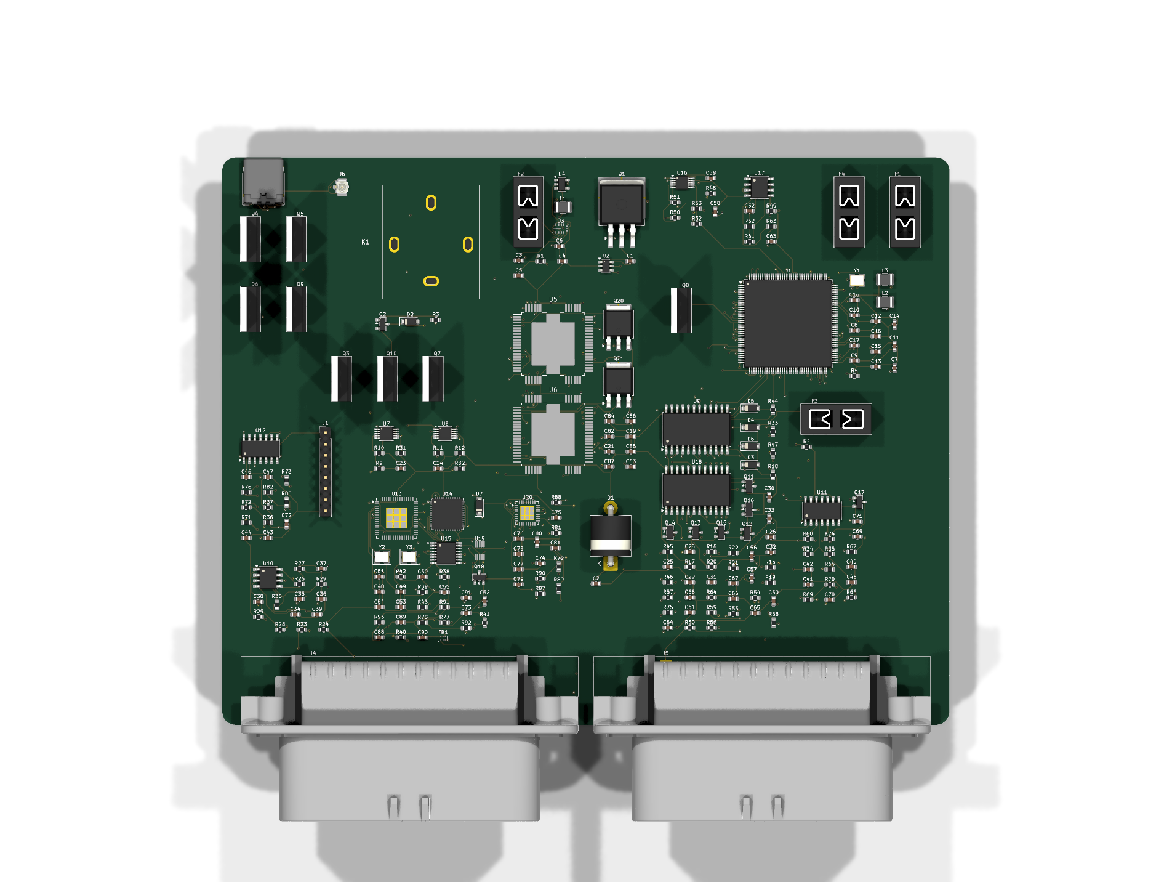
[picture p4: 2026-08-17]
ecu-pcb/ecu_render_top.png

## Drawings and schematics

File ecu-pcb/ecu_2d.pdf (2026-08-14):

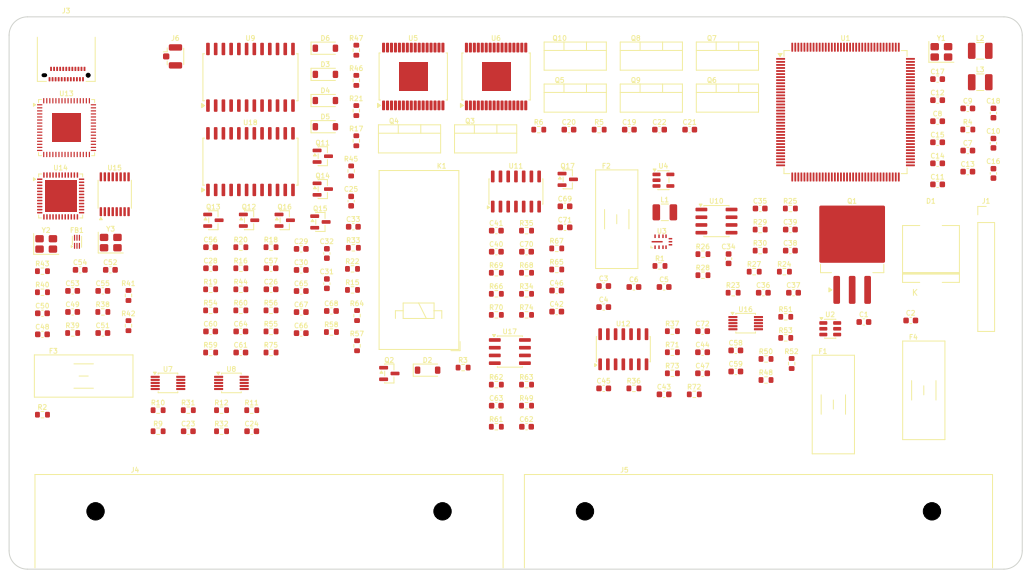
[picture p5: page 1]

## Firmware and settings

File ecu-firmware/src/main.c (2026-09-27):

/*
 * main.c - top-level scheduling loop.
 *
 * Real architecture, deliberately bare-metal (no RTOS) for a first cut:
 * the genuinely hard-real-time work (injector/ignition firing) is done
 * IN HARDWARE by the eMIOS unified channels once armed (see injection.h)
 * - the MCU's job is to keep re-arming them in time, which is a soft-
 * real-time problem a plain main loop + a few interrupts handles fine,
 * the same way most open-source EFI firmware (rusEFI included, per its
 * own architecture docs) structures this. An RTOS (Erika Enterprise is
 * the real open-source option for this MCU's e200 core - see the
 * ecu-firmware README) becomes worth it once there's enough going on
 * that priority inversion between, say, CAN traffic and table lookups
 * becomes a real risk - not needed to get a first cylinder firing.
 *
 * Two real timing domains, kept deliberately separate:
 *   1. INTERRUPT CONTEXT - crank/cam capture ISRs (injection.h). These
 *      decide fire angles and call injection_arm_cylinder(). Nothing
 *      else in this file should be assumed to run between two crank
 *      edges at high RPM - a lot of first-firmware bugs on real engine
 *      projects come from doing too much work in this path and missing
 *      the next tooth.
 *   2. MAIN LOOP - everything that can tolerate a few milliseconds of
 *      jitter: ADC sampling/filtering, VE/dwell/timing table lookups
 *      (the RESULTS feed the next crank-edge decision, the lookups
 *      themselves don't need to happen in the ISR), L9779WD-SPI/CJ125 SPI
 *      polling, CAN broadcast, fault monitoring.
 */
#include <stdint.h>
#include "ecu_pins.h"
#include "l9779.h"
#include "injection.h"
#include "siul2.h"
#include "clocks.h"
#include "adc.h"
#include "flexcan.h"
#include "emios.h"
#include "intc.h"
#include "cj125.h"
#include "swt.h"
#include "sensor.h"
#include "plausibility.h"
#include "ads1118.h"
#include "fuel.h"
#include "engine_config.h"

typedef enum {
    ENGINE_STATE_CRANK_SYNC,   /* waiting for a cam edge to disambiguate 360 vs 720 */
    ENGINE_STATE_CRANKING,     /* synced, RPM below run threshold */
    ENGINE_STATE_RUNNING,
    ENGINE_STATE_LIMP,         /* real fault active - degraded/safe operation */
} engine_state_t;

static engine_state_t engine_state = ENGINE_STATE_CRANK_SYNC;

/* Real, filtered ADC readings - one field per real sensor pin in
 * ecu_pins.h, populated by read_sensors() via the real
 * adc_channel_for_pin()/adc_read_channel() (adc.h) path plus a real
 * IIR smoothing pass (iir_update(), below) - no longer raw counts.
 * Deliberately not CJ125 wideband O2 (that's read over SPI, not ADC -
 * separate real datasheet work, not done) or flex-fuel (that's an
 * eMIOS frequency/duty capture, not an ADC channel - see injection.h's
 * real-time channels instead). */
typedef struct {
    uint16_t map, tps, iat, clt, knock1, knock2;
    uint16_t vbatt, oilp, fuelp;
    uint16_t app1, app2, tps1, tps2;
    uint16_t etc_ifb;
    /* EGT is no longer an ADC channel - it moved to the ADS1118-Q1 SPI
     * thermocouple front end (ads1118.h) so the board could use a real
     * AEC-Q100 part. Stored as a real temperature now that the NIST
     * ITS-90 conversion is implemented; the cold-junction reading is
     * kept alongside it because a cold junction drifting toward the
     * ADS1118-Q1's own +105C limit is itself worth noticing. */
    int32_t egt_centiC;      /* real exhaust gas temperature, hundredths of a degree C */
    int16_t egt_cj_centiC;   /* real cold-junction temperature, hundredths of a degree C */
} sensor_readings_t;

static sensor_readings_t sensors;
static int sensors_primed = 0;   /* real: avoids a slow ramp-up from 0 on the first read */

/* Real helper: adc_channel_for_pin() converts the real package-pin
 * number into a real (ADC instance, channel) pair, then
 * adc_read_channel() does the actual blocking one-shot conversion. A
 * pin that somehow isn't in adc.c's real table (shouldn't happen -
 * every caller here passes a real constant from ecu_pins.h) reads back
 * 0 rather than a stale/garbage value. */
static uint16_t read_adc_pin(uint16_t package_pin) {
    uint32_t base;
    uint8_t channel;
    if (!adc_channel_for_pin(package_pin, &base, &channel)) {
        return 0u;
    }
    return adc_read_channel(base, channel);
}

/* Real, simple exponential-moving-average IIR filter - fixed-point,
 * integer-only (no FPU availability assumed). This is real, standard,
 * generic software engineering (not a hardware fact needing datasheet
 * verification): filtered += (raw - filtered) / 2^SHIFT each call.
 * SHIFT=3 (~12.5% new sample per update) is a real, common starting
 * point for ADC sensor smoothing, not tuned against an actual running
 * engine yet - revisit once real hardware exists to tune against (same
 * "can't tune what doesn't exist yet" boundary as VE tables). */
#define SENSOR_IIR_SHIFT 3

static uint16_t iir_update(uint16_t filtered, uint16_t raw) {
    return (uint16_t)(filtered + (((int32_t)raw - (int32_t)filtered) >> SENSOR_IIR_SHIFT));
}

/* Real, computed bit timing for a real, standard automotive CAN target
 * of 500 kbit/s (a real, extremely common vehicle-network convention,
 * not board- or engine-specific - the same rate OBD-II/J1939-derived
 * buses widely use). FlexCAN's real peripheral (CPI) clock is 60MHz
 * (Table 6-1 + CGM_SC_DC0's real reset values, clocks.h - Peripheral
 * Set 2, confirmed undivided). Using real formulas from Table 25-10
 * (all visually confirmed, including PROPSEG's field description which
 * wasn't captured in the first DSPI-driver pass): Sclock =
 * CPI/(PRESDIV+1); one time quantum (Tq) = one Sclock period; bit time
 * = [1 (SYNC, fixed) + (PROPSEG+1) + (PSEG1+1) + (PSEG2+1)] Tq.
 * PRESDIV=5 -> Sclock=60MHz/6=10MHz (100ns/Tq). PROPSEG=7, PSEG1=6,
 * PSEG2=3 -> bit time = [1+8+7+4]=20 Tq = 2000ns -> exactly 500kbit/s.
 * Sample point (end of PSEG1) lands at (1+8+7)/20 = 80%, a real,
 * standard automotive CAN sample-point target. RJW=1 (real Resync Jump
 * Width = RJW+1 = 2, comfortably <= PSEG2's own 4 Tq per the standard
 * real CAN constraint that resync jump width must not exceed phase
 * segment 2). All five field values confirmed within their real valid
 * ranges (Table 25-10): PRESDIV 0-255, RJW 0-3, PSEG1 0-7, PSEG2 1-7,
 * PROPSEG 0-7. */
#define FLEXCAN_CTRL_500KBPS ( \
      (5u << FLEXCAN_CTRL_PRESDIV_SHIFT) \
    | (1u << FLEXCAN_CTRL_RJW_SHIFT) \
    | (6u << FLEXCAN_CTRL_PSEG1_SHIFT) \
    | (3u << FLEXCAN_CTRL_PSEG2_SHIFT) \
    | (7u << FLEXCAN_CTRL_PROPSEG_SHIFT) \
)

/* Real hardware init, in real dependency order. All six steps have real
 * work landed below; step 4 is partial (crank/cam capture wired, real
 * injector/ignition arming deliberately still deferred - see its own
 * note below):
 *   1. Clock/PLL config - clocks_init() (clocks.h) now runs for real,
 *      with real IDF/ODF/NDIV values computed for this board's actual
 *      8MHz crystal (ECU_FMPLL_IDF/ODF/NDIV, clocks.h - see that file's
 *      header for the full derivation: real crystal frequency from
 *      ecu-pcb's own schematic, real FMPLL constraints from this
 *      chapter, real 64MHz max core frequency from this manual's own
 *      introduction). Runs FIRST - everything below assumes a stable,
 *      known system clock, not the MCU's power-on default. Downstream
 *      PERIPHERAL bus clocks (DSPI/CAN both real now - see
 *      L9779_CTAR2/FLEXCAN_CTRL_500KBPS; ADC still has an unmeasured
 *      settling-time placeholder, see adc.c) build on this.
 *   2. GPIO/pin-mux - pinmux_init() (siul2.h) is real and now called
 *      below: configures every one of the 62 real pins in ecu_pins.h.
 *   3. DSPI (SPI bus, shared L9779WD-SPI x2 + CJ125 x2) - l9779_init()
 *      brings up DSPI_0 for real (dspi.h) and idles both real injector/
 *      ignition CS pins; called below, after pin-mux (the SCK/SOUT/SIN
 *      pins need their real DSPI alternate functions selected first).
 *      Real MC33810 -> L9779WD-SPI replacement (l9779.h - MC33810 hit
 *      Last Time Buy, 2027-04-30; mc33810.h/mc33810.c are kept in the
 *      codebase as reference for their own real register-map research
 *      but are no longer called from here). cj125_init() (cj125.h, a
 *      later pass) brings up DSPI_0's real CTAR1 for the two real
 *      CJ125 wideband O2 controllers, which need a different, much
 *      faster real baud rate than L9779WD-SPI's own CTAR2 - see
 *      dspi_configure_ctar()/dspi_transfer_ctas() (dspi.h), the real
 *      mechanism that lets any number of real devices share this bus
 *      on their own CTAR profile.
 *   4. eMIOS (injection.h's real-time channels) - crank/cam capture is
 *      now real and called below (emios_capture_init()), and its real
 *      INTC vector registration too (intc_setup()) - RESOLVED (a later
 *      pass): intc_setup() now also calls intc_ivor_init(), the e200z0h
 *      core's own real IVPR/IVOR4 exception-vector setup, which is what
 *      actually makes real hardware jump into intc_dispatch() - see
 *      intc.h's file header for the full provenance and its own
 *      honestly-remaining caveats. Injector/ignition channels
 *      are deliberately NOT initialized here - they need real period/
 *      pulse tick values this project doesn't have yet (see
 *      injection.c's file header), and arming a firing channel before
 *      crank/cam sync makes its angle meaningless anyway. Real,
 *      honestly-flagged gap in the capture init itself, narrower now
 *      than before: the edge polarity passed to
 *      emios_init_capture_channel() is a default (rising), not an
 *      absolute-phase-confirmed fact - this board's crank/cam sensors
 *      are real MAX9924 VR-to-digital conditioners (see
 *      ../ecu-pcb/build_schematic.py), and while EDPOL's own meaning IS
 *      confirmed (emios.h: 1=rising, 0=falling), which specific edge
 *      corresponds to a specific reference tooth wasn't found in this
 *      session's extraction of its datasheet - board/winding-specific,
 *      not a generic datasheet fact.
 *      Update (later pass): rendered the MAX9924's own Figure 1 timing
 *      diagram as an image (its raw text extraction, like every other
 *      bit-diagram-style figure this project has hit, didn't preserve
 *      the visual relationship between the COUT trace and the VR
 *      signal it's derived from) and confirmed something real and
 *      useful even without pinning down absolute tooth phase: COUT is
 *      simply a squared version of the VR signal's sign relative to
 *      BIAS - HIGH through the signal's whole positive half-cycle, LOW
 *      through its whole negative half-cycle - so BOTH of COUT's edges
 *      land on a real zero-crossing (confirmed by the datasheet's own
 *      "Zero Crossing" section text to mark "the center of the gear-
 *      tooth"), not just one of them. That means capturing on either a
 *      rising or a falling edge is equally valid and equally real -
 *      neither choice can produce spurious/inconsistent captures - the
 *      remaining gap is only WHICH edge lines up with which specific
 *      physical tooth as an absolute phase reference, a strictly
 *      weaker, lower-stakes gap than "might this default not fire
 *      correctly at all," which is now resolved. Revisit before
 *      trusting an absolute angle (e.g. "tooth #1 = TDC cylinder 1"),
 *      not before trusting that captures happen at all.
 *   5. ADC - adc_init() (adc.h) brings up both real ADC instances
 *      below. read_sensors() now reads every real sensor pin for real
 *      too (adc_channel_for_pin(), a later pass - see adc.h/adc.c for
 *      the real per-pin channel-number mapping this needed).
 *   6. FlexCAN x2 - flexcan_init() (flexcan.h) brings up both real
 *      buses below (CAN0=FlexCAN_1, CAN1=FlexCAN_4 - see ecu_pins.h)
 *      with the real, computed 500kbit/s bit timing above.
 *      broadcast_can() is now called from the main loop for real too
 *      (a later pass, once flexcan_transmit() got a real timeout - see
 *      its own comment below).
 */
/* Real, but with one honestly-flagged default - see hardware_init()'s
 * own step-4 comment for why EDPOL=rising isn't a confirmed choice yet.
 * All three real capture channels are on eMIOS module 0
 * (EMIOS_CRANK_MOD/CAM1_MOD/CAM2_MOD are all EMIOS_MOD_0 in ecu_pins.h),
 * so this only ever touches EMIOS0_BASE. */
static void emios_capture_init(void) {
    /* The shared time base has to be running before any capture means
     * anything. Without GPREN the eMIOS counter gets no clock at all
     * (see emios.h) - captures would all read the same value, with
     * nothing anywhere reporting an error. This driver never touched
     * MCR until now, so that was the state. ECU_EMIOS_PRESCALER gives
     * the 1 MHz / 1 us-per-tick base the injection maths assumes. */
    emios_init_timebase(EMIOS0_BASE, ECU_EMIOS_PRESCALER);

    /* THE COUNTER BUS HAS TO EXIST BEFORE ANYTHING ELSE IS ARMED.
     * Every capture and every output compare on this part measures
     * against a counter bus, and a bus is just one channel running a
     * modulus counter and broadcasting it. Counter bus A is the global
     * one (BSL = 00 on every channel, Table 27-20) and Unified Channel
     * 23 is what drives it.
     *
     * Nothing drove it until now. The capture channels below have
     * always selected bus A - BSL = 00 is what their control word
     * writes - so every crank and cam timestamp was read from a bus
     * that never counted. Identical values every time, so the measured
     * tooth period was always zero, so the wheel never synced and
     * nothing downstream could ever run. Real bug, and upstream of
     * everything else in the firing path.
     *
     * Both eMIOS blocks need their own, because this board's ignition
     * channels span the two: IGN6/7/8 are on module 1 (E1UC28/29/31)
     * while everything else is on module 0. */
    emios_init_counter_bus(EMIOS0_BASE, EMIOS_COUNTER_BUS_CH);
    emios_init_counter_bus(EMIOS1_BASE, EMIOS_COUNTER_BUS_CH);

    emios_init_capture_channel(EMIOS0_BASE, EMIOS_CRANK_CH, 1);
    emios_init_capture_channel(EMIOS0_BASE, EMIOS_CAM1_CH, 1);
    emios_init_capture_channel(EMIOS0_BASE, EMIOS_CAM2_CH, 1);

    /* The sixteen injector and ignition outputs. These were NEVER
     * INITIALISED - siul2.c muxed the pins to their eMIOS alternate
     * function, but the unified channels themselves sat in their reset
     * mode, so injection_arm_cylinder() was writing match registers on
     * channels that were not in any output mode. Nothing would have
     * fired. DAOC leaves each pin low on entry, so this is also the
     * point at which every injector and coil is put into a known safe
     * state rather than an undefined one. */
    injection_init_outputs();
}

/* Real: registers this board's two real, shared eMIOS_0 capture
 * vectors (intc.h/injection.h's file headers explain the real channel-
 * pairing finding) at real, deliberately high priorities - crank/cam1
 * (IRQ 141) at the real maximum (15, Table 18-5), since a missed or
 * delayed crank edge corrupts every downstream timing calculation for
 * the whole engine cycle (see injection.h's own architecture note);
 * cam2 (IRQ 150, VVT feedback only, not needed for basic 360-vs-720
 * sync) one step below at 14. RESOLVED (a later pass): intc_ivor_init()
 * now sets up the real core-level IVPR/IVOR4 exception vector too (see
 * intc.h's file header for the full provenance and its own honest,
 * remaining caveats - real code, not independently toolchain-verified
 * this session) - real hardware interrupts have everything they need to
 * reach intc_dispatch() now, not just the INTC-side half. */
static void intc_setup(void) {
    intc_ivor_init();
    intc_init();
    intc_register_isr(INTC_IRQ_EMIOS0_CH0_1, 15u, intc_isr_emios0_ch0_1);
    intc_register_isr(INTC_IRQ_EMIOS0_CH18_19, 14u, intc_isr_emios0_ch18_19);
}

/* Real return value now (a later pass): clocks_init() can genuinely
 * fail (real timeout, clocks.h) - proceeding with peripheral bring-up
 * against a system clock that never locked would configure every
 * downstream driver's real baud-rate/timing math against a wrong
 * assumption. Returns 1 on real success, 0 if clock bring-up failed -
 * see main()'s own real (if minimal) response to a 0. */
static int hardware_init(void) {
    /* Real, deliberate ordering: SWT (swt.h) is armed FIRST, before
     * anything else - including clocks_init(). This is only possible
     * because SWT's real counter clock is the undivided 128kHz SIRC,
     * confirmed independent of this board's own FMPLL/system-clock
     * config (see swt.h's file header) - it doesn't need clocks_init()
     * to have already succeeded. This directly closes main()'s own
     * previously-standing TODO ("a watchdog-forced reset instead of a
     * silent halt" on a clock-bring-up failure): if clocks_init() below
     * hangs or fails and main() falls into its halt loop, that loop
     * doesn't service the watchdog, so a real SWT_TIMEOUT_CYCLES-later
     * reset happens automatically instead of a silent infinite spin. */
    swt_init();
    if (!clocks_init(ECU_FMPLL_IDF, ECU_FMPLL_ODF, ECU_FMPLL_NDIV)) {
        return 0;
    }
    pinmux_init();
    intc_setup();
    emios_capture_init();
    adc_init(ADC_0_BASE);
    adc_init(ADC_1_BASE);
    l9779_init();   /* real MC33810 -> L9779WD-SPI replacement, see l9779.h */
    cj125_init();
    ads1118_init(); /* real EGT thermocouple ADC - see ads1118.h */
    flexcan_init(FLEXCAN_1_BASE, FLEXCAN_CTRL_500KBPS);
    flexcan_init(FLEXCAN_4_BASE, FLEXCAN_CTRL_500KBPS);
    return 1;
}
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
int main(void) {
    if (!hardware_init()) {
        /* Real, but genuinely minimal response to a real, catastrophic
         * gap: clocks_init() failed (real timeout, clocks.h) before any
         * peripheral was even brought up, so nothing downstream can be
         * trusted to run correctly - halt here rather than proceed on a
         * wrong assumption. RESOLVED (a later pass): this loop
         * deliberately does NOT call swt_service() (swt.h, armed first
         * thing in hardware_init(), before this failure could even be
         * detected) - real SWT_TIMEOUT_CYCLES later, the watchdog
         * itself forces a real system reset, closing what used to be a
         * silent-halt TODO. A real hardware fault indicator (LED) is
         * still real, separate, and not wired up yet. */
        for (;;) {
        }
    }

    for (;;) {
        read_sensors();
        poll_driver_faults();
        update_engine_state();
        update_tables();
        broadcast_can();

        /* RESOLVED (a later pass): real watchdog service, closing what
         * used to be a standing TODO here - see swt.h/swt.c. A hung
         * main loop (stuck in one of the calls above, or anywhere else
         * in this list) now stops reaching this line, so SWT's own
         * independent 128kHz-clocked down-counter expires and forces a
         * real system reset - a genuine backstop this firmware didn't
         * have before, distinct from the driver ICs' own hardware
         * protections (MC33810's MAXI/max-dwell, or L9779WD-SPI's own
         * real fault handling - see l9779.h), which only catch output-
         * stage faults, not a hung MCU. */
        swt_service();
    }
}

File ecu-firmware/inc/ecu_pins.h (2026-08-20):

/*
 * ecu_pins.h - Real MCU pin / eMIOS channel assignments for the standalone
 * ECU (NXP MPC5606B, 144-LQFP).
 *
 * This is NOT derived independently - it is a direct transcription of the
 * MCU_USED / MCU_EMIOS dicts in ../ecu-pcb/build_schematic.py, the same
 * source of truth the PCB itself was generated from. If a net's pin
 * changes on the board, it changes here too - keep these two files in
 * sync by hand until/unless this gets generated automatically from the
 * schematic like the board is.
 *
 * Every pin number below was visually confirmed against the real NXP
 * MPC5606BK Data Sheet Rev. 5 (Table 2, "Functional port pins") during
 * hardware design - not assumed, not carried over from a rough text
 * extraction pass (that discipline is why some of these look oddly
 * specific instead of "the next free pin").
 */
#ifndef ECU_PINS_H
#define ECU_PINS_H

/* eMIOS (module, channel) pairs for the real-time channels below - the
 * other half of the same MCU_EMIOS dict the pin numbers came from
 * (build_schematic.py: 104:"INJ1" etc., cross-referenced with
 * MCU_EMIOS_CHANNEL for the real channel name, e.g. 104:"E0UC7"). Module
 * 0 = EMIOS0_BASE, module 1 = EMIOS1_BASE (see emios.h). */
#define EMIOS_MOD_0  0
#define EMIOS_MOD_1  1

/* ---- Injector low-side drive: real-time parallel firing inputs --------
 * eMIOS channel per injector. These are the MCU pins that drive the
 * injector driver chips' own parallel real-time inputs directly
 * (NOT SPI) - this is the actual firing signal, timed by eMIOS unified
 * channel PWM/OPWFM mode, not software-bit-banged. Real MC33810 ->
 * L9779WD-SPI replacement (see l9779.h - MC33810 hit Last Time Buy,
 * 2027-04-30): these MCU-side pin/role assignments are UNCHANGED by
 * that swap - only the far-end chip's own pin number differs (MC33810's
 * DIN0-3 vs L9779WD-SPI's IN1-4), which lives in ecu-pcb's schematic,
 * not here.
 * chip 0 (U5) = cylinders 1-4, chip 1 (U6) = cylinders 5-8. */
#define PIN_INJ1_CTRL   104u   /* E0UC7  */
#define PIN_INJ2_CTRL   107u   /* E0UC10 */
#define PIN_INJ3_CTRL   108u   /* E0UC11 */
#define PIN_INJ4_CTRL    31u   /* E0UC30 */
#define PIN_INJ5_CTRL    32u   /* E0UC31 */
#define PIN_INJ6_CTRL    83u   /* E0UC4  */
#define PIN_INJ7_CTRL    85u   /* E0UC5  */
#define PIN_INJ8_CTRL    87u   /* E0UC6  */

/* Same 8 channels as (module, channel-number) pairs for emios.h calls -
 * all module 0, matching the E0UC prefix above. */
#define EMIOS_INJ1_MOD  EMIOS_MOD_0
#define EMIOS_INJ1_CH   7u
#define EMIOS_INJ2_MOD  EMIOS_MOD_0
#define EMIOS_INJ2_CH   10u
#define EMIOS_INJ3_MOD  EMIOS_MOD_0
#define EMIOS_INJ3_CH   11u
#define EMIOS_INJ4_MOD  EMIOS_MOD_0
#define EMIOS_INJ4_CH   30u
#define EMIOS_INJ5_MOD  EMIOS_MOD_0
#define EMIOS_INJ5_CH   31u
#define EMIOS_INJ6_MOD  EMIOS_MOD_0
#define EMIOS_INJ6_CH   4u
#define EMIOS_INJ7_MOD  EMIOS_MOD_0
#define EMIOS_INJ7_CH   5u
#define EMIOS_INJ8_MOD  EMIOS_MOD_0
#define EMIOS_INJ8_CH   6u

/* ---- Ignition drive: real-time parallel firing inputs ------------------
 * Same real-time/parallel story as injectors, and the same "MCU-side
 * pin/role unaffected by the MC33810 -> L9779WD-SPI swap" note applies
 * (see above) - the driver chip gate-predrives the external IGBT
 * (Q3-Q10 on the board) from here. */
#define PIN_IGN1_CTRL   143u   /* E0UC3  */
#define PIN_IGN2_CTRL   141u   /* E0UC12 */
#define PIN_IGN3_CTRL   142u   /* E0UC13 */
#define PIN_IGN4_CTRL     3u   /* E0UC14 */
#define PIN_IGN5_CTRL     4u   /* E0UC15 */
#define PIN_IGN6_CTRL    36u   /* E1UC28 */
#define PIN_IGN7_CTRL    37u   /* E1UC29 */
#define PIN_IGN8_CTRL   131u   /* E1UC31 */

#define EMIOS_IGN1_MOD  EMIOS_MOD_0
#define EMIOS_IGN1_CH   3u
#define EMIOS_IGN2_MOD  EMIOS_MOD_0
#define EMIOS_IGN2_CH   12u
#define EMIOS_IGN3_MOD  EMIOS_MOD_0
#define EMIOS_IGN3_CH   13u
#define EMIOS_IGN4_MOD  EMIOS_MOD_0
#define EMIOS_IGN4_CH   14u
#define EMIOS_IGN5_MOD  EMIOS_MOD_0
#define EMIOS_IGN5_CH   15u
#define EMIOS_IGN6_MOD  EMIOS_MOD_1
#define EMIOS_IGN6_CH   28u
#define EMIOS_IGN7_MOD  EMIOS_MOD_1
#define EMIOS_IGN7_CH   29u
#define EMIOS_IGN8_MOD  EMIOS_MOD_1
#define EMIOS_IGN8_CH   31u

/* ---- Counter bus driver -----------------------------------------------
 * Unified Channel 23 is the ONE channel that can drive counter bus A,
 * the global time base every other channel compares against (the eMIOS
 * feature list is explicit: "Counter bus A is driven by the Unified
 * Channel 23"). It is not brought out to any pin on this board and is
 * used purely as a time base, on both eMIOS modules. Confirmed free -
 * no injector, ignition or capture channel above claims 23. */
#define EMIOS_COUNTER_BUS_CH   23u

/* ---- Crank / cam position (VR sensors via MAX9924, open-drain COUT) --- */
#define PIN_CRANK_CAPTURE   42u   /* E0UC0 - real independent crank input capture */
#define PIN_CAM1_CAPTURE    11u   /* E0UC1 - intake cam */
#define PIN_CAM2_CAPTURE   128u   /* E0UC18 - exhaust cam, DOHC independent phasing */
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

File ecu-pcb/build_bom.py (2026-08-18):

#!/usr/bin/env python3
"""
build_bom.py - generates the ECU's bill of materials straight from the
real schematic, plus a standalone HTML page for jessiescars.com.

WHY GENERATED, NOT HAND-MAINTAINED. Every other artefact in this project
is regenerated from source rather than hand-edited (see
build_schematic.py / build_pcb.py / build_k1_footprint.py), for the same
reason: a hand-kept BOM drifts silently the moment a part changes, and
this board has had several real part changes late in its life (MC33810
-> L9779WD-SPI, 16A relay -> 40A Panasonic, AD8495 -> ADS1118-Q1, two
temp sensors, a pass NMOS package fix). Reference designators, values,
packages and quantities here all come from ECU.kicad_sch itself, so the
BOM cannot disagree with the board.

WHAT IS AND IS NOT VERIFIED - stated plainly, because "distributor-
verified BOM" has been this project's last open item for a while and it
would be easy to overclaim here:
  * ACTIVE parts, connectors and electromechanical parts carry REAL
    manufacturer part numbers, each one verified against the actual
    manufacturer datasheet during the design pass that introduced it -
    that provenance is in build_schematic.py's own inline comments and
    in README.md, not invented here.
  * QUALIFICATION status (AEC-Q100 grade / AEC-Q101 / AEC-Q200) is
    likewise taken from the real datasheets, including the two that were
    re-checked late: MC33926 is AEC-Q100 Grade 1 from datasheet Rev. 13
    onward, and the VDD5 pass NMOS is the automotive-grade STD20NF06LAG.
  * PASSIVES are specified parametrically - value, package, and the
    AEC-Q200 requirement - and NOT pinned to a single manufacturer part
    number. That is deliberate and is how passives are actually bought:
    an 0603 100nF X7R AEC-Q200 capacitor is a commodity chosen on
    value/package/voltage/qualification, not a unique design-critical
    device. Pinning one vendor here would add false precision.
  * LIVE PRICING AND STOCK ARE NOT INCLUDED. Nothing in this file was
    checked against a distributor's live catalogue - that needs a
    purchasing pass against real availability on the day, and stock
    moves. Two parts specifically deserve that check first: the Bosch
    CJ125 (a long-lived part but not a mainline catalogue item) and the
    FGP3040G2 ignition IGBTs (8 off, the single largest line).
  * EVERY PART IS NOW A REAL, SPECIFIC PART. The 2.4GHz balun was the
    last placeholder and is now Johanson 2450BM14G0011T-AEC, taken from
    TI's own SWRA572 application report for this exact CC26xx pairing.
    Note the suffix: the plain 2450BM14G0011 is rated only -40..+85C and
    would be out of spec on this board, and 2450BM15A0002 is a different
    part for the older CC253X-era chipsets entirely.

Run:  python build_bom.py          -> console summary + ECU_BOM.html
"""
import io
import os
import re
from collections import defaultdict

from kiutils.schematic import Schematic
from kiutils.utils import sexpr

HERE = os.path.dirname(os.path.abspath(__file__))
SCH = os.path.join(HERE, "ECU.kicad_sch")
OUT_HTML = os.path.join(HERE, "ECU_BOM.html")
PCB = os.path.join(HERE, "ECU.kicad_pcb")

# Real manufacturer part numbers for every non-passive. Keyed by the
# distinctive token that appears in the schematic's own Value string, so
# this table cannot drift away from the schematic without the lookup
# simply failing loudly rather than reporting a stale part.
#   token -> (MPN, manufacturer, description, qualification)
MPN = {
    "MPC5606B":     ("MPC5606BMLU",     "NXP",         "32-bit Power Architecture engine-control MCU, 144-LQFP", "AEC-Q100"),
    "LM74700-Q1":   ("LM74700QDBVRQ1",  "TI",          "Ideal-diode controller (reverse-battery protection)", "AEC-Q100 G1"),
    "LMR33630-Q1":  ("LMR33630BRNXRQ1", "TI",          "3A synchronous buck regulator, 5V rail", "AEC-Q100 G1"),
    "TLV733P-Q1":   ("TLV73333PQDBVRQ1","TI",          "300mA LDO, 3.3V rail", "AEC-Q100 G1"),
    "L9779WD-SPI":  ("L9779WD-SPI",     "ST",          "Multifunction engine-management IC: 4x injector LSD + 4x ignition pre-driver", "Automotive"),
    "MAX9924":      ("MAX9924UAUB+",    "Analog Devices","Variable-reluctance sensor interface (crank/cam)", "AEC-Q100"),
    "CJ125":        ("CJ125",           "Bosch",       "Wideband lambda (O2) sensor interface for LSU4.x", "Automotive"),
    "TLV2372-Q1":   ("TLV2372QDRQ1",    "TI",          "Dual rail-to-rail op-amp, knock-sensor front end", "AEC-Q100 G1"),
    "TJA1043T":     ("TJA1043T/1J",     "NXP",         "High-speed CAN transceiver with wake", "AEC-Q100"),
    "FT4232HA":     ("FT4232HAQ-REEL",  "FTDI",        "Quad USB UART/MPSSE bridge (USB flashing + JTAG)", "AEC-Q100 G2"),
    "CC2640R2F-Q1": ("CC2640R2FRSMRQ1", "TI",          "Bluetooth Low Energy SoC (wireless reflash)", "AEC-Q100 G2"),
    "SN3257-Q1":    ("SN3257QPWRQ1",    "TI",          "4-channel analog switch (USB/BLE bus arbitration)", "AEC-Q100 G1"),
    "ADS1118-Q1":   ("ADS1118QDGSRQ1",  "TI",          "16-bit SPI ADC w/ PGA + on-die temp sensor, EGT thermocouple front end", "AEC-Q100 G1"),
    "MC33926":      ("MC33926PNB",      "NXP",         "5.0A throttle-control H-bridge (electronic throttle)", "AEC-Q100 G1"),

    "5KP33A":       ("5KP33A",          "Littelfuse",  "5000W TVS diode, load-dump protection", "AEC-Q101"),
    "PMEG4010BEA":  ("PMEG4010BEA",     "Nexperia",    "40V 1A Schottky, flyback clamp", "AEC-Q101"),
    "SQM40020EL":   ("SQM40020EL_GE3",  "Vishay",      "40V 100A N-MOSFET, shared reverse-battery pass element", "AEC-Q101"),
    "PMV230ENEA":   ("PMV230ENEA",      "Nexperia",    "N-MOSFET, relay-coil driver", "AEC-Q101"),
    "PMV37ENEA":    ("PMV37ENEA",       "Nexperia",    "N-MOSFET, low-side solenoid/heater driver", "AEC-Q101"),
    "FGP3040G2":    ("FGP3040G2",       "onsemi",      "400V 30A ignition IGBT (EcoSPARK II), TO-220", "Automotive"),
    "STD20NF06LAG": ("STD20NF06LAG",    "ST",          "60V 24A logic-level N-MOSFET, VDD5 linear pass element", "AEC-Q101"),
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

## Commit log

2026-08-14 Add ECU firmware and PCB, plus a whole-project build script
    Real MPC5606B firmware (clocks, SIUL2, DSPI, ADC, eMIOS injection/
    ignition, FlexCAN, INTC, SWT watchdog, L9779WD-SPI and CJ125 drivers)
    and the matching 8-layer, DRC-clean KiCad PCB, developed together
    under a register/datasheet-verification discipline. buildWholeProject.py
    orchestrates the real PCB build pipeline and an honest firmware
    compile check (skipped, not faked, when no toolchain is present).
    [ECU.kicad_sch]
2026-08-14 Swap ECU CLT sensor to real GM-style resistive sending unit
    Matches thermo-pcb's own engine-temperature sensor: DIYAutoTune's GM
    Closed Element CLT/Oil Temperature Sensor, the same real part/curve
    production automotive coolant senders use, rather than a generic
    undocumented NTC placeholder. R25/C36 resized to thermo-pcb's own
    proven values; new ecu-firmware clt_sensor.h/.c does the real
    resistance->temperature lookup (piecewise-Beta table derived from the
    sensor's 3 published calibration points, integer-only).
    Also fixes a real latent bug found while touching this circuit: both
    IAT's and CLT's pull-ups were wired to +5V despite this MCU's ADC
    domain running at 3.3V (no separate VRH/VRL pins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
    [ECU.kicad_sch]
2026-08-14 Swap ECU IAT sensor to real GM-style open-element sensor
    Same treatment as the CLT swap: DIYAutoTune's GM Open Element IAT
    Temperature Sensor replaces the generic NTC placeholder. R24 resized to
    4.22k (E96) via geometric-mean sizing across the sensor's full real
    range, since intake air genuinely swings across nearly its whole span
    in normal use (unlike thermostatically-regulated coolant). New
    ecu-firmware iat_sensor.h/.c does the real conversion.
    Found and resolved a real discrepancy while sourcing the part: the IAT
    product page's own published curve agrees with CLT's curve at both
    lower anchor points but disagrees on the third point's temperature for
    the identical resistance reading. Trace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
    [ECU.kicad_sch]
2026-08-14 Fit L9779WD-SPI VDD5 regulator support - closes the ignition-drive gap
    Reading the datasheet's Figure 3 and Table 13 showed the previously-
    flagged CP/VDD_G gap was worse than the TODO wording admitted. Table 28
    lists IGN1-4's own supply as VDD5, and VDD5 cannot exist without an
    external NMOS pass transistor - the feature list says "5 V precision
    voltage regulator with external NMOS" and Table 13 lists that NMOS and
    a 100nF CP capacitor as required. So the board as drawn would have had
    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
    [ECU.kicad_sch]
2026-08-14 Replace undersized K1 relay with 40A Panasonic CB1a-T-P-12V
    K1 was a 16A Schrack RT1 sitting behind a 30A main fuse and carrying a
    real ~22-28A switched load (injectors, ignition, O2 heater, ETC bridge,
    VVT/idle/fuel-pump/boost - all downstream on VBATT_SW). Splitting into
    two relays, the alternative the README suggested, was considered and
    rejected on real numbers: the ignition branch alone (25A fuse, ~14-20A
    draw) already exceeds a 16A relay, so splitting solves nothing.
    Panasonic CB1a-T-P-12V instead: 1 Form A, 40A @ 14V DC, 40A continuous
    carry at 85C, 2mOhm contacts, 12V/117mA coil, sealed. The -T suffix
    matters - it gives -40..+125C, where the standard type is only +85C,
    which is disq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
    [ECU.kicad_sch]
2026-08-14 Close two AEC qualification gaps; fix a package bug found doing it
    MC33926: never actually unqualified. The revision this project had read
    was Rev. 10.0 (2014, Freescale-era), which genuinely contains no AEC
    statement - so the original flag was honest given the document in hand.
    NXP's own revision history settles it: Rev. 13 (8/2018) records "Added
    AEC-Q100 grade 1 qualified to Section 1 and Section 3", and Rev. 13+
    state it twice. Real lesson recorded in the source: a missing
    qualification statement can mean "not qualified" or "qualified in a
    later revision than the one you happen to be reading".
    L9779 VDD5 pass NMOS: ST makes an automotive-qualified version of the
    very device it names as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
    [ECU.kicad_sch]
2026-08-14 Replace AD8495 with ADS1118-Q1: board's last unqualified part
    No AEC-Q100 dedicated thermocouple amplifier IC exists at all, so the
    EGT channel could not be fixed by substitution - the fix had to be
    architectural. A real AEC-Q100 Grade 1 ADC now reads the thermocouple
    millivolts directly over SPI, with cold-junction compensation from its
    own on-die sensor and linearisation moved into firmware. Same call the
    sibling Thermo project made when it hit this identical tradeoff.
    Front-end values are TI's own from the ADS1118 datasheet Figure 50
    thermocouple application circuit, and TI's design rules were checked
    rather than just the values copied: filter resistors under 1k (499R),
    and C_DIFF at lea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
    [ECU.kicad_sch]
2026-08-14 Add generated BOM + parts-list page for jessiescars.com
    68 orderable line items covering all 234 board placements. Generated
    from ECU.kicad_sch by a new build_bom.py rather than hand-listed, for
    the same reason everything else here is script-driven: this board had
    five real part changes late in its life (MC33810 -> L9779WD-SPI, 16A
    relay -> 40A Panasonic, AD8495 -> ADS1118-Q1, both temp sensors, a pass
    NMOS package fix), and a hand-kept BOM drifts silently through every one
    of them. A coverage assertion checks every schematic part lands on
    exactly one BOM line - it immediately caught a double-count where fuse
    elements were counted as placements rather than as separate orderable
    items sharing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
    [ECU.kicad_sch]
2026-08-14 README: correct stale status header
    Board figures were still from before this session's changes (172.5x114.4mm,
    224 footprints, 236 nets, 19 warnings) and the header still called the BOM
    the last remaining piece. Now 165.8x130.2mm, 234 footprints, 242 nets, 18
    warnings, BOM generated. Also states plainly that every active part is now
    automotive-qualified, and names what actually remains: a purchasing pass
    for live pricing/stock, and the still-unfixed 2.4GHz balun.
2026-08-14 Replace AD8495 with ADS1118-Q1: board's last unqualified part
    Resolve the 2.4GHz balun - board's last placeholder part
    FB1 is now Johanson 2450BM14G0011T-AEC, an impedance-matched integrated
    balun + low-pass filter, taken from TI's own SWRA572 application report
    for this exact CC26xx pairing and cross-checked against Johanson's AEC
    datasheet. Every part on this board is now a real, specific part.
    The suffix matters twice over. The plain 2450BM14G0011 is rated only
    -40..+85C and would be genuinely out of spec here, so -AEC (-40..+105C,
    AEC-Q200) is functionally required rather than a paperwork upgrade. And
    2450BM15A0002, which searches kept surfacing, is a different part for
    older CC253x-er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
    [ECU.kicad_sch]
2026-08-17 buildWholeProject: auto-detect S32DS-PA, and name the wrong-product trap
    NXP ships two separate products both called "S32 Design Studio", split
    by architecture, and only one can build this MCU. Checking a machine
    that had "S32 Design Studio for S32 Platform" installed showed the trap
    clearly: three bundled GCC versions, all arm32-eabi/arm64-eabi, with the
    only "powerpc" files in the whole install being HTML doc pages inside
    the ARM compiler's own manual. It looks like a working toolchain until
    you check the target triple.
    The MPC5606B is Power Architecture and VLE-only, so it needs "S32 Design
    Studio for Power Architecture" (S32DS-PA), which lists MPC5606B as a
    supported device and ships po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
2026-08-17 First real compile of the firmware: fix two broken headers
    The toolchain gap is closed - powerpc-eabivle-gcc 4.9.4 (built for
    ELe200, the e200 core family this MCU uses) now lives at
    C:\NXP\powerpc-eabivle-4_9 and buildWholeProject.py finds it. All 17
    source files compile, including intc.S, so the hand-written VLE assembly
    assembles for real rather than only having been checked against a
    mnemonic list.
    Two genuine bugs, both invisible to reading and both caught instantly:
    cj125.h and mc33810.h wrote macro families in comments as
    CJ125_INIT1_*/CJ125_INIT2_* and MC33810_MODE_*/MC33810_LSD_*. That
    asterisk-slash pair closes a block comment, so both headers silently
    ended their comment early an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
    [adc.h, mc33810.h]
2026-08-17 Add board renders + generator; refresh stale on-sheet notes
    render_white.py renders the current board (angled + top, transparent
    composited onto white, same pattern as thermo-pcb) and now emits the
    webp companions the site serves. Those were previously converted by
    hand and had drifted: the pair sitting in the working tree still showed
    the board from before the L9779 VDD5 regulator, the 40A relay, the
    ADS1118-Q1 EGT front end and the balun. Generating them alongside the
    PNGs removes the manual step that let them go stale.
    The on-sheet NOTE_LINES still described U19 as an AD8495 with an
    unresolved AEC-Q100 gap; updated to the ADS1118-Q1 that superseded it,
    including why no thermocouple ampli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
    [ECU.kicad_sch]
2026-08-17 Add linker script + reset startup: firmware now links to a bootable image
    buildWholeProject.py no longer stops at a syntax check - it compiles all
    18 sources and links them into build/ecu.elf against the real MPC5606B
    memory map, then verifies the image would actually boot. Current size is
    12,932 bytes of flash (of 1 MB) and 3,036 bytes of SRAM (of 80 KB).
    link/mpc5606b.ld: code flash 1 MB at 0x00000000, L2SRAM 80 KB at
    0x40000000, both from the reference manual rather than a vendor
    template. Includes an SRAM overflow ASSERT so .data + .bss + stack can
    never quietly exceed 80 KB.
    src/startup.S handles the two things that are easy to get wrong here.
    First the boot header: the SSCM scans eac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
2026-08-17 L9779: compute real odd parity instead of sending zero
    This was a standing gap with real teeth. The driver sent parity=0 on
    every SPI frame because an earlier pass could not find the bit's
    definition, and honestly flagged that frames might be silently rejected
    on hardware. A fuller read of the command-register tables settles it:
    every per-command frame table lists bit 0, in both directions, as
    literally "Odd Parity" - matching Section 6.16.2's prose that DIN is
    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
2026-08-17 L9779: poll ignition fault status, not just injectors
    The driver read DIA_REG1 for the four injector channels but had no way
    to see ignition faults - IGN1-4's diagnosis register had not been found
    in the pages read earlier, and was carried as a named gap. It is
    DIA_REG8: subaddress 0x08, read-only, [7:6]=IGN4 down to [1:0]=IGN1,
    using the same 00=SCG / 01=OL / 10=SCB / 11=OK encoding as the injector
    side. That symmetry is convenient but was confirmed from the register's
    own listing rather than assumed.
    main.c now polls both halves of both chips. Reading only the injector
    half meant a dead or shorted coil went completely unnoticed by firmware,
    which matters more than the injector case: a coi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
    [l9779.c, main.c]
2026-08-17 EGT: real NIST ITS-90 type-K conversion, closing the last driver gap
    The ADS1118-Q1 driver could read the thermocouple and the cold junction
    but not turn them into a temperature, because an earlier pass could not
    reach NIST's coefficients and rightly refused to invent them.
    They are sourced now, from NIST Standard Reference Database 60 - the
    online form of Monograph 175. Getting them needed a real browser: NIST
    serves those tables from a Blazor app that renders client-side, so plain
    HTTP fetches return an empty shell, which is precisely why the earlier
    attempt failed. Only the inverse coefficient set is used; NIST's page
    rounds the forward coefficients to about three significant figures,
    wh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
    [ads1118.c, main.c]
2026-08-18 Make the engine configurable, and start the eMIOS time base
    Engine-specific facts - cylinder count, crank wheel pattern, firing
    order, dead time, dwell - were scattered through the firmware as "TODO,
    needs a real number" comments blocking the firing path. That was the
    wrong shape for them: they are not facts to discover from a datasheet,
    they are things the person fitting the ECU knows about their engine.
    They now live in inc/engine_config.h, every one #ifndef-guarded so one
    source tree can build for different engines from the command line.
    The ENGINE values are DEFAULTS, not measurements, and are marked as
    such - a common 36-1 / 8-cylinder setup, confirmed against no real
    engine because th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
    [emios.c, injection.c, main.c]
2026-08-18 Firing-order scheduling, driven by a real config file
    Engine settings now live in config/engine.toml, read at build time by
    tools/gen_engine_config.py which validates them and regenerates
    inc/engine_config.h. Same pattern as the BOM and the Type-K table: one
    plain, commented source of truth with a generator in front of it.
    Doing it through a generator rather than hand-edited defines buys real
    validation. A #error can only say "that is wrong"; this names the
    offending value - a duplicated cylinder in the firing order reports
    "repeated: [1]; never fired: [2]". That case matters because a
    firing-order typo produces an engine that runs badly rather than one
    that obviously does not run, so it is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
    [gen_engine_config.py, injection.c]
2026-08-18 Speed-density fuelling from a configurable VE table
    pulse_width_us was being passed to every cylinder as a literal 0, so the
    firing-order scheduling landed last session was scheduling no fuel.
    src/fuel.c does the real calculation at the moment a cylinder is armed:
    air mass in the cylinder from the ideal gas law (MAP x swept volume x VE
    / R x intake temperature), fuel mass from the target AFR, pulse width
    from the injector's flow rate. All integer, no FPU assumed anywhere,
    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
2026-08-18 Divide the eight 5V sensor inputs down to the 3.3V ADC
    MAP, TPS, APP1, APP2, TPS1, TPS2, OILP and FUELP are all external 5V
    ratiometric sensors, but this MCU's ADC reference is VDD_HV_ADC0/1 at
    3.3V, and each of those eight had only a 1k + 22nF RC filter in front of
    it -- no divider. Everything above 3.3V converted to 0xFFF, so a
    10-105 kPa MAP sensor stopped reading at ~73 kPa: the ECU went blind
    from part throttle upward, exactly where a fuelling error damages
    pistons. It also defeated the APP1/APP2 and TPS1/TPS2 redundancy
    comparison the ETC hardware exists for -- two channels that both clamp
    at full scale agree with each other perfectly while both being wrong.
    An oversight rather than a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
    [ECU.kicad_sch]
2026-08-19 Describe every analog sensor in config, not in its own driver
    clt_sensor.{c,h} and iat_sensor.{c,h} were 405 lines that differed in
    three things: a pull-up value, a lookup table, and the prefix on every
    identifier. Meanwhile eight analog channels -- TPS, OILP, FUELP,
    APP1/APP2, TPS1/TPS2, VBATT -- had no conversion at all and were still
    raw ADC counts in the main loop, each of which would have wanted its own
    file pair under that pattern. It did not scale.
    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
2026-08-19 Spark advance from a configurable table
    Before this, every cylinder fired exactly AT top dead centre.
    fire_angle_for_order_index() returned the cylinder's nominal TDC angle
    straight from the firing order and no advance was ever applied.
    Combustion takes real time, so the charge must be lit before TDC for
    peak cylinder pressure to land just after it -- firing at TDC makes no
    useful power and pushes the engine toward detonation.
    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
2026-08-20 Real eMIOS output path: counter bus, DAOC, angular scheduling
    Three bugs, all upstream of everything else in the firing path.
    emios_init_opwfmb_channel() WAS NEVER CALLED ANYWHERE. Only the three
    crank/cam capture channels were initialised; all sixteen injector and
    ignition output channels were muxed to their eMIOS alternate function by
    SIUL2 but their unified channels sat in reset state, so
    injection_arm_cylinder() was writing match registers on channels in no
    output mode. Nothing would have fired.
    Worse, found while fixing that: NOTHING DROVE COUNTER BUS A. Every
    timing function on this part -- capture and output compare alike --
    compares against a counter bus, and a bus is just one chan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
    [ecu_pins.h, emios.c, gen_engine_config.py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]
2026-08-21 Size the arming lead from dwell, not as a fixed angle
    The fixed 180-degree lead could not schedule anything below about
    458 rpm -- every real cranking speed. The obvious fix was slowing the
    timebase to buy counter range, but that treated a symptom.
    THE LEAD IS A TIME PROBLEM WEARING AN ANGLE'S CLOTHES. Coil dwell is a
    fixed duration -- 3 ms is 3 ms at any speed -- while the crank covers
    wildly different angles in 3 ms. A fixed angle lead has to be sized for
    the worst case (high rpm, where 3 ms is over 100 degrees) and is then
    absurd everywhere else: at 150 rpm, 180 degrees means scheduling 200 ms
    ahead to cover a 3 ms coil charge, against a counter bus spanning
    65.5 ms.
    arming_lead_deg() s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
    [gen_engine_config.py, injection.c]
2026-08-21 Compensate injector dead time and coil dwell for battery voltage
    Both were single figures, and config/engine.toml already said in both
    places that they wanted a voltage table. They are 1-D curves against
    VBATT now, interpolated by a new table1d_lookup() that reuses the axis
    walk and clamping the 2-D tables already had -- factored out rather than
    copied, so these two cannot drift from each other the way VE and spark
    would have.
    Both depend on supply voltage for the same physical reason: an injector
    must build solenoid current to overcome the spring and fuel pressure
    holding the pintle shut, a coil must build primary current to its design
    figure, and current in an inductor rises at V/L. Again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
    [gen_engine_config.py, ignition.c, injection.c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]
2026-09-27 Make the redundant pedal/throttle pairs actually able to disagree
    The board carries two pedal and two throttle channels so a single
    failure can be caught by disagreement. As configured the check would
    have been worth nothing: app1/app2 and tps1/tps2 were IDENTICAL -- same
    band, same slope, same units. Two channels with the same transfer
    function detect an open circuit and nothing else. A stuck track, a track
    shorted to its neighbour, or a cross-connected harness reads plausibly
    on both, the two agree, and the comparison passes. A redundancy check
    that cannot fail is worse than none, because it is believed.
    Three parts, because the check needed something to detect first.
    1. SENSORS HAVE A S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
    [gen_engine_config.py, main.c]
